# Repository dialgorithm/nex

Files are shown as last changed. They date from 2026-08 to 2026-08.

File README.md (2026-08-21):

# nex

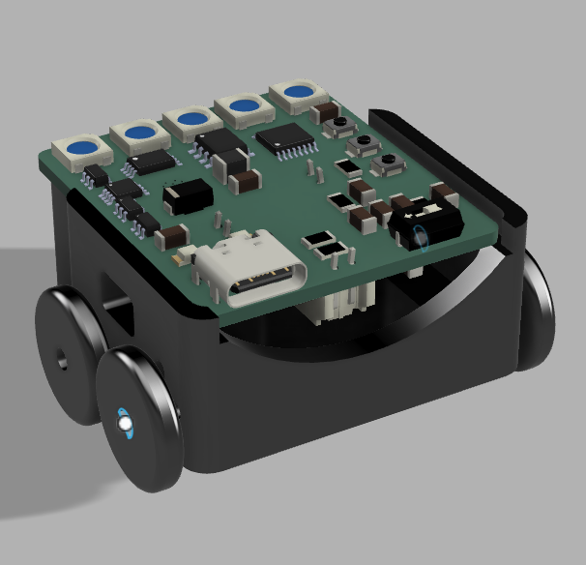
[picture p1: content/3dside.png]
3d side


**nex** is a swarm robotics project built around **ESP32-based bots**, computer vision, AprilTags, and a custom 4-layer PCB. The goal is to have multiple small bots identify and communicate with each other while working together as a swarm.

it features:

- ESP32-WROOM in each bot for wireless communication
- Luckfox Lyra Zero W for computer vision
- AprilTags for identifying individual bots
- Custom 4-layer PCB designed in KiCad

## how it works

each bot has an **ESP32-WROOM** which handles communication between the bots and provides the wireless connection. Each bot also has its own AprilTag, giving the vision system a way to identify which bot it is looking at.

the **Luckfox Lyra Zero W** handles the computer vision side. It detects the AprilTags and uses their position and orientation to work out where the other bots are.

this allows the bots to know who is around them and where they are, which forms the basis for the swarm behaviour.

## KiCad

the electronics are built around a custom **4-layer PCB**, designed to keep the different parts of the bot connected without needing a large amount of external wiring.

| schematic | PCB |
| :---: | :---: |
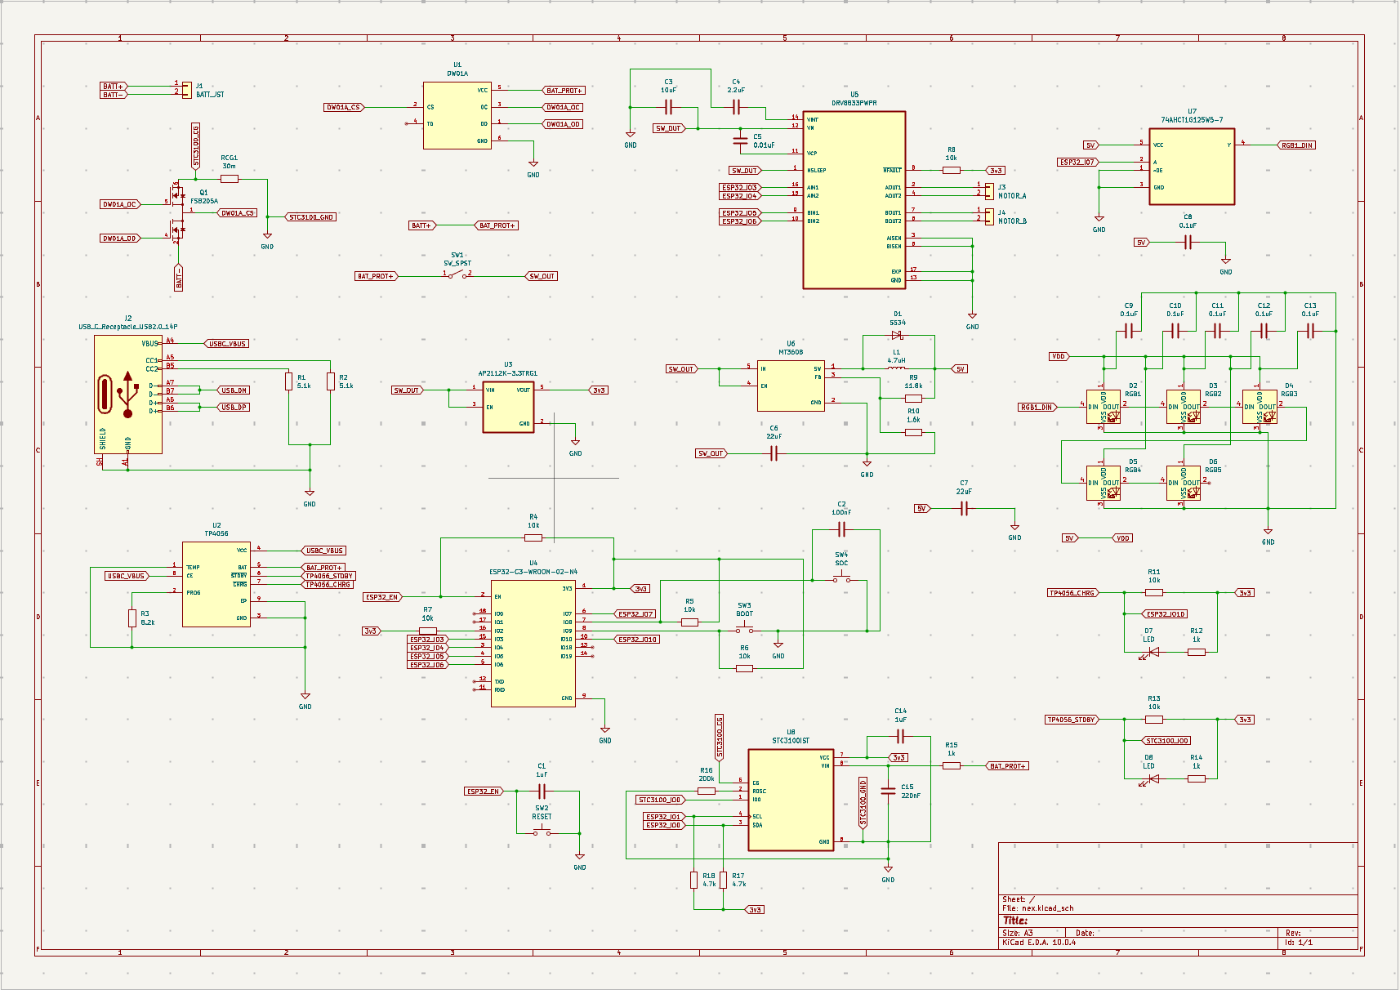
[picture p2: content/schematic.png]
schematic
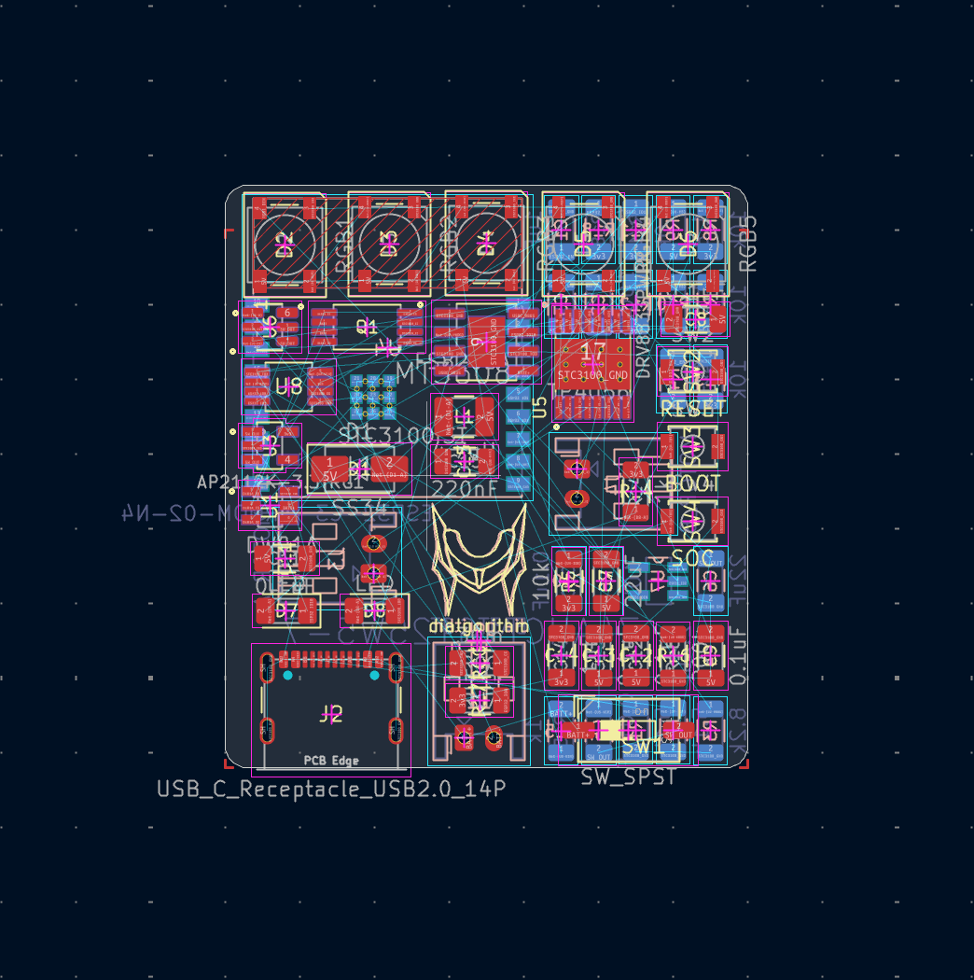
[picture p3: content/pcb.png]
PCB
|  |  |

| PCB mockup top | PCB mockup bottom |
| :---: | :---: |
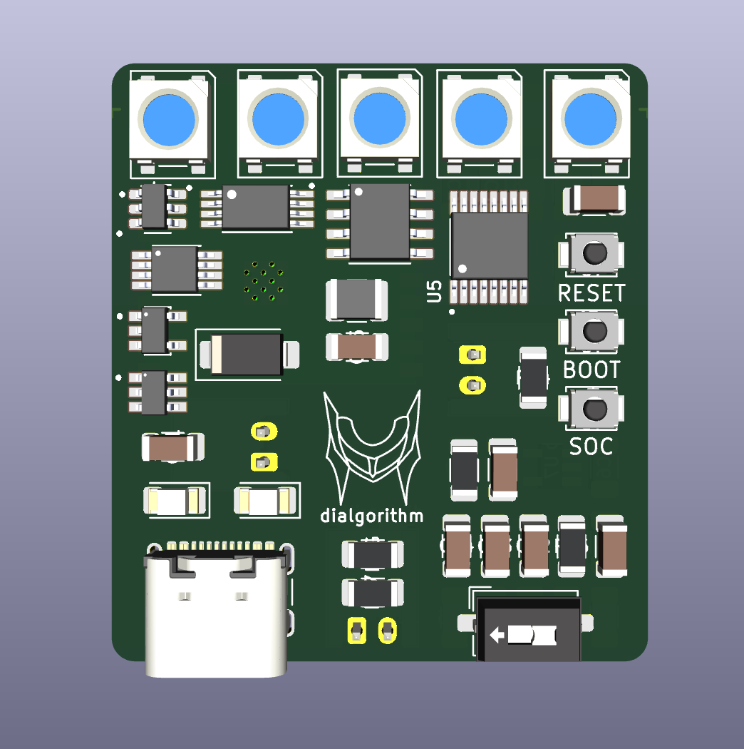
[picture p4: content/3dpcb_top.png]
top
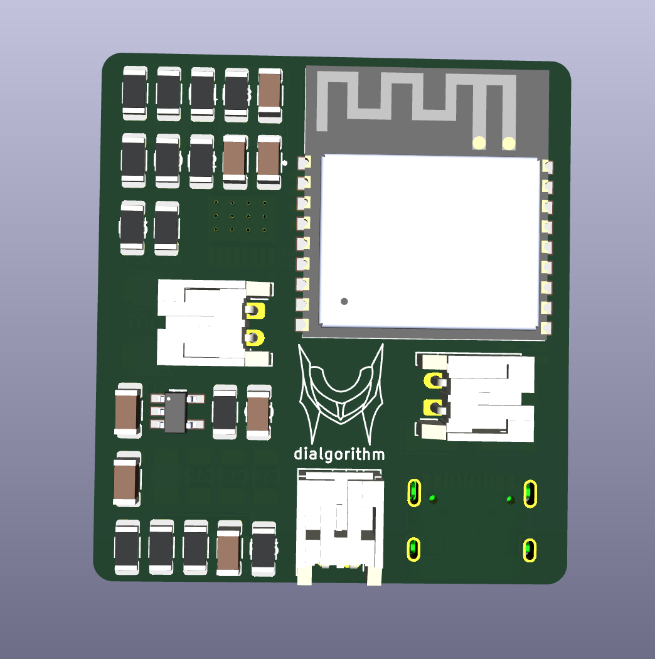
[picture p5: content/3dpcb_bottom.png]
bottom
|  |  |

## Fusion

the mechanical design and overall bot layout were modelled in Fusion.

| top | side | bottom |
| :---: | :---: | :---: |
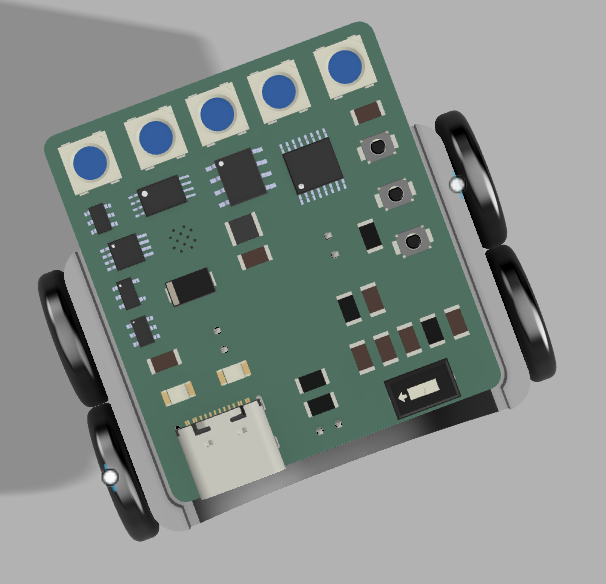
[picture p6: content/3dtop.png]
3d top
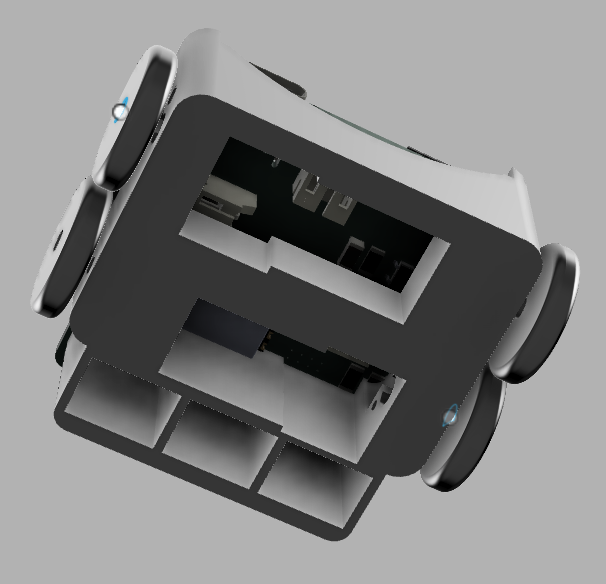
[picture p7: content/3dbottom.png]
3d bottom
|  | 3d side |  |

## BOM

the complete bill of materials is available in [`bom.csv`](bom.csv).

## firmware

firmware is not included yet. The software will be added after the physical bots are built and the hardware can be tested and debugged.

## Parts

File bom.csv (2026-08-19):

Item | Quantity | Cost | Source
PCB | 10 | $34 | https://robu.in/product/online-pcb-manufacturing-service/
1uF 1206 SMD | 20 | $5 | https://www.amazon.in/1UF-1206-Ceramic-Capacitor-20Pcs/dp/B0DYJTLFDL
0.1uF 1206 SMD | 60 | $4.2 | https://www.amazon.in/Steko-Capacitor-Tolerance-Electronic-Component/dp/B0D3D8HW51
220nF 1206 SMD | 10 | $2.7 | https://www.amazon.in/220NF-Ceramic-Capacitor-WALSIN-0-22UF/dp/B0GDDTYT3W
100nF 1206 SMD | 10 | $3.25 | https://www.amazon.in/e4u-Ceramic-Capacitor-SMD-1206-Package/dp/B09QGXCYWB
10uF 1206 SMD | 10 | $3 | https://www.amazon.in/10uF-Ceramic-Capacitor-25pcs-CL31A106KAHNNNE/dp/B0GDF194MR
2.2uF 1206 SMD | 10 | $2.6 | https://www.amazon.in/2-2uF-0603-Ceramic-Capacitor-pack/dp/B0FCSH5MKH
0.01uF 1206 SMD | 10 | $2 | https://www.amazon.in/Steko-Capacitor-Tolerance-Electronic-Component/dp/B0FRZ43N35
22uF 1206 SMD | 20 | $4 | https://www.amazon.in/22%C2%B5F-SMD-Capacitor-Package-Original/dp/B0F4RK46GL
SS34 Diode | 10 | $2.1 | https://www.amazon.in/SS34-SMA-Schottky-Diode-Package-DO-214AC/dp/B092R2K27Q
WS2812B-2020 | 50 | $4.2 | https://robu.in/product/sme-ws2812b-2020-addressable-rgb-pixel-led-worldsemi/
RED LED 1206 SMD | 10 | $2.3 | https://www.amazon.in/Steko-Electronic-Component-Multipurpose-Backlight/dp/B0FZJ1QWR9
GREEN LED 1206 SMD | 10 | $2.3 | https://www.amazon.in/Steko-Electronic-Component-Multipurpose-Backlight/dp/B0FZJ293TX
JST Kit | 30 | $6.3 | https://www.amazon.in/MTRoyaldia-560PCS-Connector-Housing-Adapter/dp/B0GTPGBC7S
Crimping tool | 1 | $3.2 | https://www.amazon.in/BUILDSKILL-crimping-ergonomic-heavy-duty-telephone/dp/B0DVLLL2YG
USB-C Receptacle | 10 | $3.8 | https://robu.in/product/type-c-31-m-31-hroparts-5a-1-surface-mount-right-angle-16p-female-30%E2%84%8380%E2%84%83-type-c-smd-usb-connectors-rohs
4.7uH 1210 SMD | 10 | $1.6 | https://robu.in/product/lqh32pn4r7nn0l-murata-lqh32pn4r7nn0l-power-inductor-smd-4-7-%C2%B5h-1-a-shielded-1-a-lqh32pn_n0-series-1210-3225-metric/
5.1k 1206 SMD | 20 | $2.3 | https://www.amazon.in/5-1K-ohm-Resistor-1206-Package/dp/B09N427SVD
1.6k 1206 SMD | 10 | $2.4 | https://www.amazon.in/Wizzo-Tolerance-Electronic-Components-Multipurpose/dp/B0D8L24V6L
10k 1206 SMD | 70 | $2.1 | https://www.amazon.in/100PCS-Ohm-1206-Size-Resistors/dp/B07HQLRHY1
1k 1206 SMD | 30 | $2.1 | https://www.amazon.in/Resistor-1206-Package-Tolerance-Pack/dp/B0H9JFBG6L
200k 1206 SMD | 10 | $2.1 | https://www.amazon.in/Wenray-Pieces-Kilo-Tolerance-Resistor/dp/B0HB4ZV65M
4.7k 1206 SMD | 20 | $2.1 | https://www.amazon.in/Resistor-1206-Package-4-7K-Tolerance/dp/B0H9JCZXBB
8.2k 1206 SMD | 10 | $2.7 | https://www.amazon.in/e4u-0-25W-SMD-1206-Package-Resistor/dp/B0813T2HSR
11.8k 1206 SMD | 10 | $0.42 | https://robu.in/product/mfr-25fbf52-11k8-yageo-res-11k8-0-25w-axial-metal-film/
30m SMD | 10 | $1.3 | https://robu.in/product/0-03-ohm-3w-surface-mount-sense-resistor/
SW SPST | 10 | $3.9 | https://robu.in/product/2-54-1p-tppt-shou-han-1-digit-spst-24v-black-25ma-3000-times-flat-toggle-slotted-smd-dip-switches-rohs/
DW01A | 10 | $0.65 | https://robu.in/product/dw01a-4-3v-lithium-ion-lithium-polymer-battery-protection-ic-6pin-sot-23/
TP4056 | 10 | $3.2 | https://www.amazon.in/TP4056-10Pcs-SOP8-LP4056H-4056/dp/B0G4DXKGXC
MT3608 | 10 | $2.2 | https://robu.in/product/mt3608-xian-aerosemi-tech-boost-type-adjustable-2a-2v24v-sot-23-6-dc-dc-converters-rohs/
74AHCT1G125W5-7 | 10 | $3.2 | https://robu.in/product/74ahc1g125qw5-7-diodes-incorporated-8ma-1-2v5-5v-8ma-1-sot-25-buffers-drivers-receivers-transceivers-rohs/
AP2112K-3.3TRG1 | 10 | $14.2 | https://www.desertcart.in/products/808664101-10pcs-ap2112k-3-3-sot23-5-ap2112k-3-3trg1-3
DRV8833PWPR | 10 | $26 | https://www.desertcart.in/products/525842950-reland-sun-10pcs-drv8833pwpr-htssop16-drv8833pwp-htssop-16-drv8833-tssop16
Pi Zero Case | 1 | $3 | https://www.amazon.in/REES52-RS1009-01-Raspberry-Zero-Starter/dp/B07L93QMD6
Pi Zero Camera | 1 | $3 | https://robu.in/product/5mp-raspberry-pi-camera-module-w-hbv-ffc-cable/
Luckfox Lyra Zero W (pi zero unavailable everywhere) | 1 | $41 | https://robu.in/product/luckfox-lyra-zero-w-micro-linux-development-board/
Tripod | 1 | $2.2 | https://www.amazon.in/Kratos-Extendable-Bluetooth-Multifunctional-OnePlus/dp/B0G4MZ85QG
Cable | 1 | $2 | https://www.amazon.in/Portronics-Charging-Transfer-Aluminium-compatible/dp/B0FVYTSCVY
a4 matte vinyl printing for apriltags | 8 | $8.5 | https://www.vistaprint.in/marketing-materials/labels-stickers/sheet-stickers
acrylic mounting plates for apriltags | 8 | $8.6 | https://robu.in/product/online-laser-cutting-service/
glue gun | 1 | $5.4 | https://www.amazon.in/IBELL-GG30-01-High-Heavy-Sticks/dp/B08863MZ8H
glue sticks | 1 | $3.5 | https://www.amazon.in/Themisto-7mm-glue-stick-pack/dp/B0CK27HQ2F
utility knife | 1 | $2.9 | https://www.amazon.in/Taparia-UK-3-Steel-Utility-Silver/dp/B073SWWKWJ
3d printed parts + shipping | 1 | $11 | https://printlegion.hackclub.com
Cost for Each Nex bot:
B3U-1000P | 3 | $1.2 | https://robu.in/product/b3u-1000p-omron-2-5mm-1-6mm-round-button-50ma-vertical-welding-3mm-spst-1-53n-12v-smd2-5x3mm-tactile-switches-rohs/
ESP32-C3-WROOM-02-N4 | 1 | $2.73 | https://robu.in/product/espressif-esp32-c3-wroom-02-n4-module/
STC3100IST | 1 | $2.55 | https://robu.in/product/stc3100ist-stmicroelectronics-battery-li-ion-supervisor-monitor-ic-i2c-interface-1-cell-2-7-v-to-5-5-v-supply-msop-8/
WLY602030 3.7V 300mAh | 1 | $1.83 | https://robu.in/product/300mah-pcm-protected-micro-li-po-battery/
N20-3V-100 RPM | 2 | $2.52 | https://robocraze.com/products/robocraze-dc6v-100rpm-gm12-n20-miniature-gear-motor-with-metal-gear
Total | 8 | $118 | -
Final Total | - | ~$368 | -

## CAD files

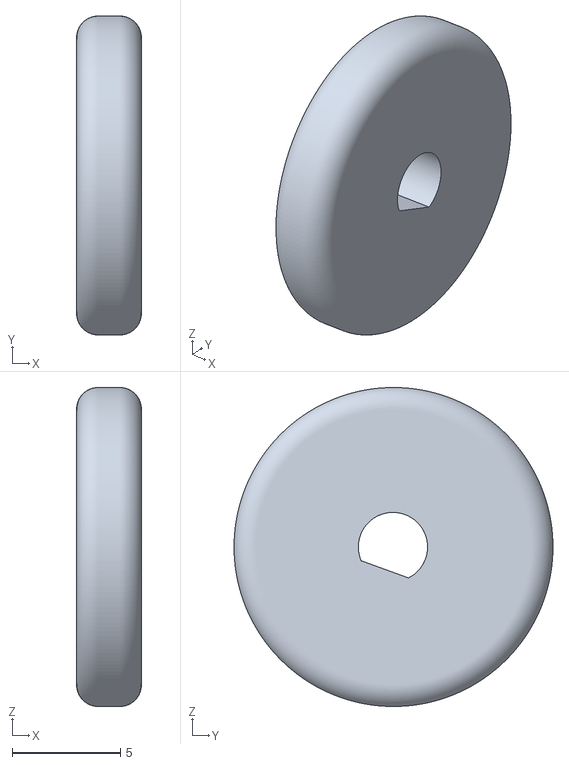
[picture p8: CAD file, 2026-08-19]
CAD/motor_wheel.stl
3.00 x 14.7 x 14.7

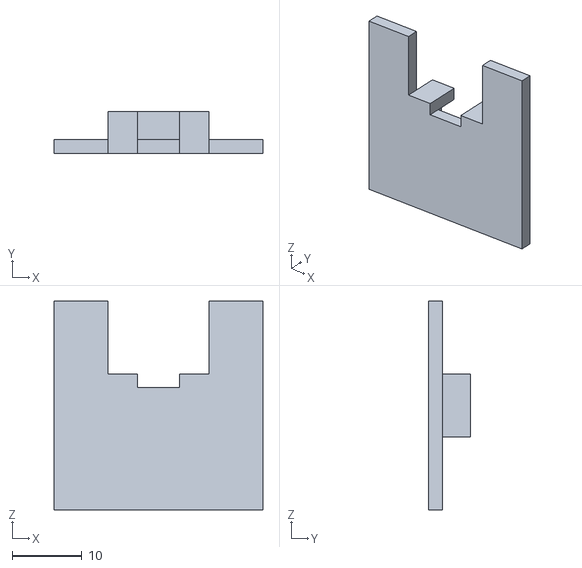
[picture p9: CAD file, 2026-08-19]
CAD/apriltag_mount.stl
30.0 x 6.00 x 30.0

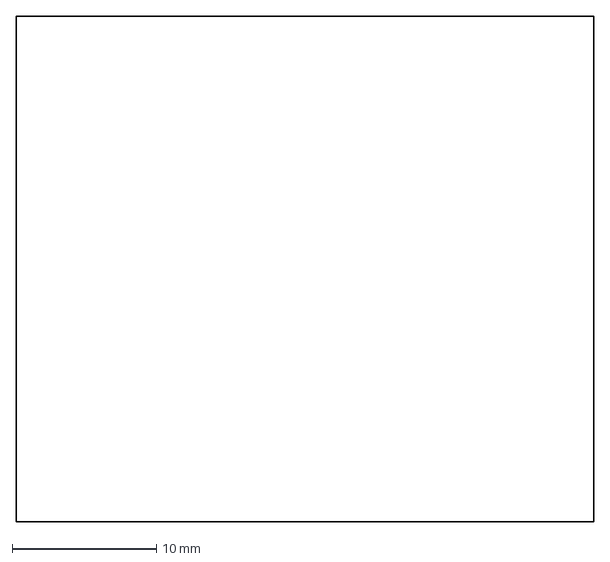
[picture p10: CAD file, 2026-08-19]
CAD/apriltag_mountpanel.dxf
40.0 x 35.0 mm

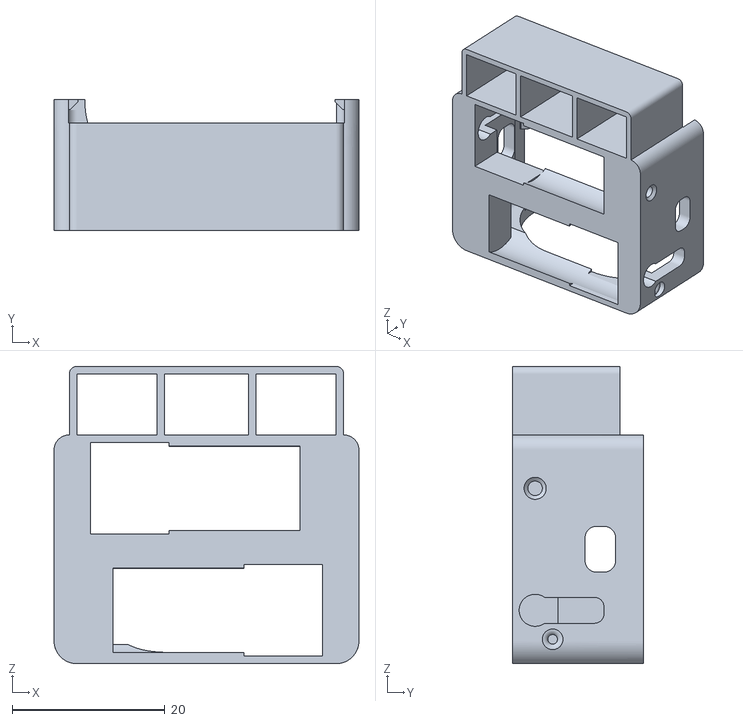
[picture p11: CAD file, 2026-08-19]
CAD/body.stl
40.0 x 17.2 x 39.0

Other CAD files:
CAD/screw_wheel.stl
CAD/main.f3z

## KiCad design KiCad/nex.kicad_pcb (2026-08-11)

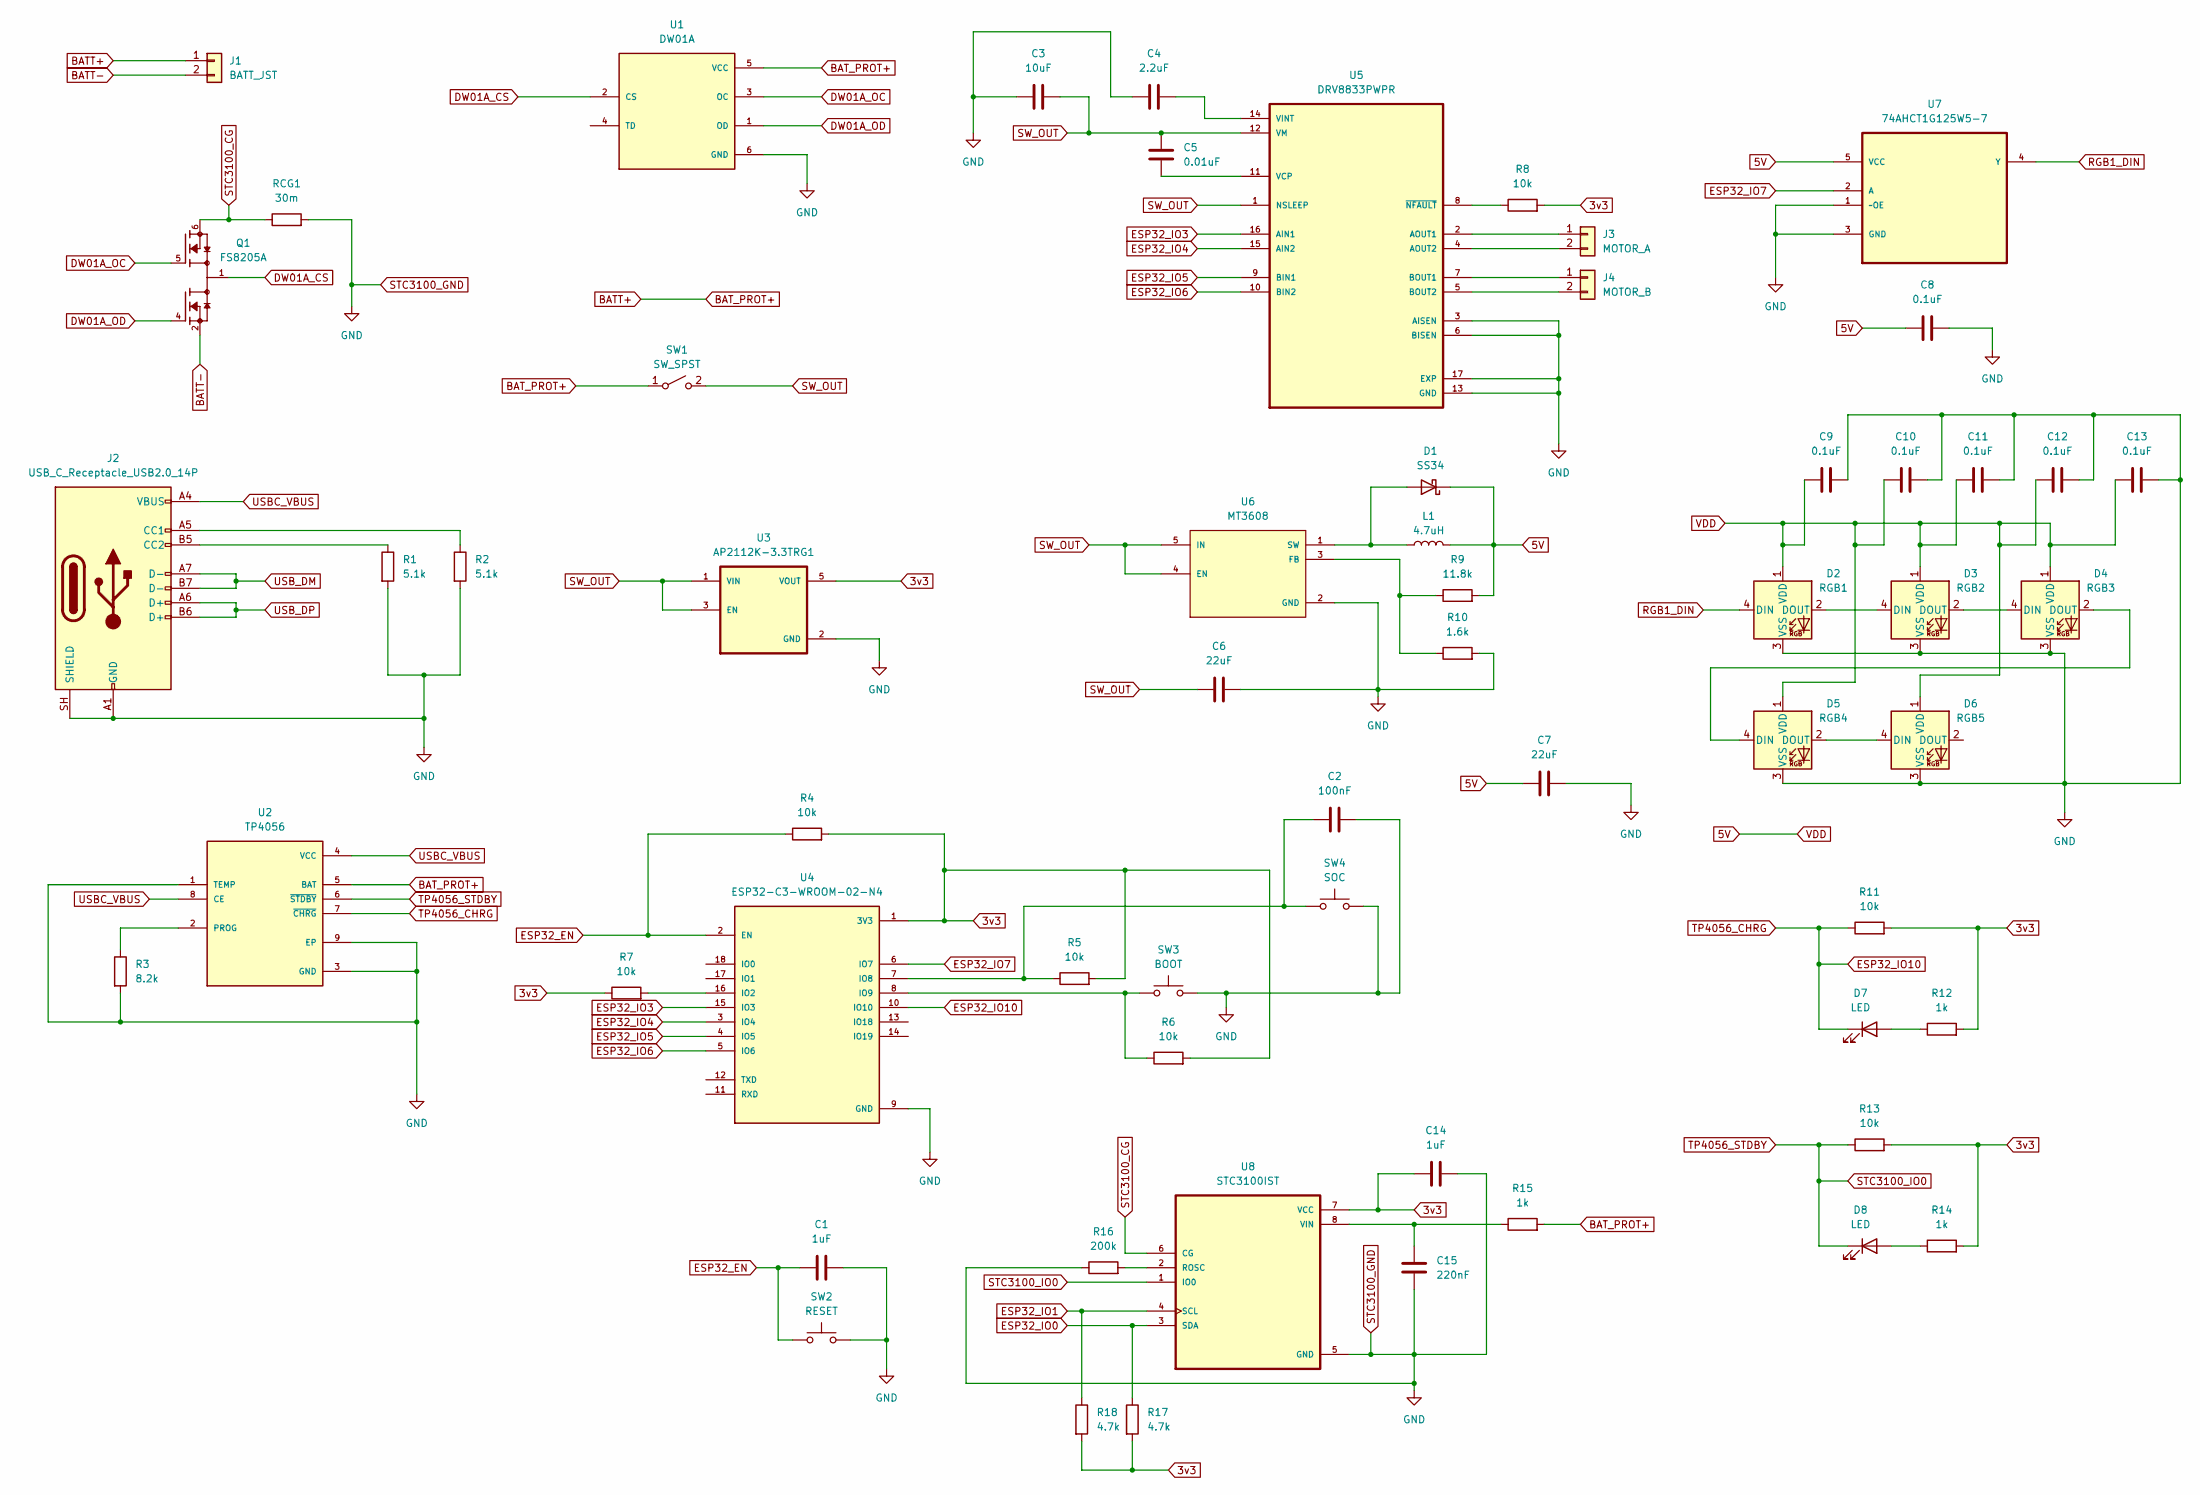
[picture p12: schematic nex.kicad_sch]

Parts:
C1, C14: 1uF; C_1206_3216Metric
C2: 100nF; C_1206_3216Metric
C3: 10uF; C_1206_3216Metric
C4: 2.2uF; C_1206_3216Metric
C5: 0.01uF; C_1206_3216Metric
C6, C7: 22uF; C_1206_3216Metric
C8, C9, C10, C11, C12, C13: 0.1uF; C_1206_3216Metric
C15: 220nF; C_1206_3216Metric
D1: SS34; D_SMA
D2: RGB1; LED_WS2812B_PLCC4_5.0x5.0mm_P3.2mm
D3: RGB2; LED_WS2812B_PLCC4_5.0x5.0mm_P3.2mm
D4: RGB3; LED_WS2812B_PLCC4_5.0x5.0mm_P3.2mm
D5: RGB4; LED_WS2812B_PLCC4_5.0x5.0mm_P3.2mm
D6: RGB5; LED_WS2812B_PLCC4_5.0x5.0mm_P3.2mm
D7, D8: LED; LED_1206_3216Metric
J1: BATT_JST; JST_PH_S2B-PH-K_1x02_P2.00mm_Horizontal
J2: USB_C_Receptacle_USB2.0_14P; USB_C_Receptacle_GCT_USB4105-xx-A_16P_TopMnt_Horizontal
J3: MOTOR_A; JST_PH_S2B-PH-K_1x02_P2.00mm_Horizontal
J4: MOTOR_B; JST_PH_S2B-PH-K_1x02_P2.00mm_Horizontal
L1: 4.7uH; L_1210_3225Metric
Q1: FS8205A; SOP65P640X120-8N; PARTREV 1.7
R1, R2: 5.1k; R_1206_3216Metric
R3: 8.2k; R_1206_3216Metric
R4, R5, R6, R7, R8, R11, R13: 10k; R_1206_3216Metric
R9: 11.8k; R_1206_3216Metric
R10: 1.6k; R_1206_3216Metric
R12, R14, R15: 1k; R_1206_3216Metric
R16: 200k; R_1206_3216Metric
R17, R18: 4.7k; R_1206_3216Metric
RCG1: 30m; R_1206_3216Metric
SW1: SW_SPST; SW_DIP_SPSTx01_Slide_6.7x4.1mm_W6.73mm_P2.54mm_LowProfile_J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
SW2: RESET; SW_SPST_B3U-1000P
SW3: BOOT; SW_SPST_B3U-1000P
SW4: SOC; SW_SPST_B3U-1000P
U1: DW01A; SOT95P280X145-6N; PARTREV 1.8
U2: TP4056; SOP127P600X175-9N
U3: AP2112K-3.3TRG1; SOT95P285X140-5N; PARTREV 2-2
U4: ESP32-C3-WROOM-02-N4; MODULE_ESP32-C3-WROOM-02-H4
U5: DRV8833PWPR; IC_DRV8833PWPR; PARTREV E
U6: MT3608; SOT95P280X145-6N; PARTREV 1.0
U7: 74AHCT1G125W5-7; SOT95P280X140-5N; MPN 74AHCT1G125W5-7
U8: STC3100IST; SOIC65P490X110-8N

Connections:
3v3: C14.1, R4.2, R5.2, R6.2, R7.1, R8.2, R11.2, R12.2, R13.2, R14.2, R17.2, R18.2, U3.5 (VOUT), U4.1 (3V3), U8.7 (VCC)
5V: C7.1, C8.1, C9.1, C10.1, C11.1, C12.1, C13.1, D1.1 (K), D2.1 (VDD), D3.1 (VDD), D4.1 (VDD), D5.1 (VDD), D6.1 (VDD), L1.2, R9.2, U7.5 (VCC)
BATT+: J1.1, R15.2, SW1.1 (A), U1.5 (VCC), U2.5 (BAT)
BATT-: J1.2, Q1.2, Q1.3
DW01A_CS: Q1.1, Q1.8, U1.2 (CS)
DW01A_OC: Q1.5, U1.3 (OC)
DW01A_OD: Q1.4, U1.1 (OD)
ESP32_EN: C1.1, R4.1, SW2.1, U4.2 (EN)
ESP32_IO0: R17.1, U8.3 (SDA)
ESP32_IO1: R18.1, U8.4 (SCL)
ESP32_IO3: U4.15 (IO3), U5.16 (AIN1)
ESP32_IO4: U4.3 (IO4), U5.15 (AIN2)
ESP32_IO5: U4.4 (IO5), U5.9 (BIN1)
ESP32_IO6: U4.5 (IO6), U5.10 (BIN2)
ESP32_IO7: U4.6 (IO7), U7.2 (A)
ESP32_IO10: D7.1 (K), R11.1, U2.7 (~CHRG), U4.10 (IO10)
unnamed: D1.2 (A), L1.1, U6.1 (SW)
unnamed: D2.2 (DOUT), D3.4 (DIN)
unnamed: D3.2 (DOUT), D4.4 (DIN)
unnamed: D4.2 (DOUT), D5.4 (DIN)
unnamed: D5.2 (DOUT), D6.4 (DIN)
unnamed: D7.2 (A), R12.1
unnamed: D8.2 (A), R14.1
unnamed: J2.A5 (CC1), R2.1
unnamed: J2.B5 (CC2), R1.1
unnamed: J3.1, U5.2 (AOUT1)
unnamed: J3.2, U5.4 (AOUT2)
unnamed: J4.1, U5.7 (BOUT1)
unnamed: J4.2, U5.5 (BOUT2)
unnamed: R3.1, U2.2 (PROG)
unnamed: R7.2, U4.16 (IO2)
unnamed: C2.1, R5.1, SW4.1, U4.7 (IO8)
unnamed: R6.1, SW3.1, U4.8 (IO9)
unnamed: C5.1, U5.11 (VCP)
unnamed: C4.2, U5.14 (VINT)
unnamed: R8.1, U5.8 (~NFAULT)
unnamed: R9.1, R10.1, U6.3 (FB)
unnamed: R16.2, U8.2 (ROSC)
unnamed: C15.2, R15.1, U8.8 (VIN)
RGB1_DIN: D2.4 (DIN), U7.4 (Y)
STC3100_CG: Q1.6, Q1.7, RCG1.1, U8.6 (CG)
STC3100_GND: C1.2, C2.2, C3.1, C4.1, C6.2, C7.2, C8.2, C9.2, C10.2, C11.2, C12.2, C13.2, C14.2, C15.1, D2.3 (VSS), D3.3 (VSS), D4.3 (VSS), D5.3 (VSS), D6.3 (VSS), J2.A1 (GND), J2.A12 (GND), J2.B1 (GND), J2.B12 (GND), J2.SH (SHIELD), R1.2, R2.2, R3.2, R10.2, R16.1, RCG1.2, SW2.2, SW3.2, SW4.2, U1.6 (GND), U2.1 (TEMP), U2.3 (GND), U2.9 (EP), U3.2 (GND), U4.9 (GND), U4.19 (GND), U4.20 (GND), U4.21 (GND), U4.22 (GND), U4.23 (GND), U4.24 (GND), U4.25 (GND), U4.26 (GND), U4.27 (GND), U4.28 (GND), U4.29 (GND), U4.30 (GND), U4.31 (GND), U4.32 (GND), U4.33 (GND), U4.34 (GND), U4.35 (GND), U4.36 (GND), U4.37 (GND), U4.38 (GND), U4.39 (GND), U5.3 (AISEN), U5.6 (BISEN), U5.13 (GND), U5.17 (EXP), U6.2 (GND), U7.1 (~OE), U7.3 (GND), U8.5 (GND)
STC3100_IO0: D8.1 (K), R13.1, U2.6 (~STDBY), U8.1 (IO0)
SW_OUT: C3.2, C5.2, C6.1, SW1.2 (B), U3.1 (VIN), U3.3 (EN), U5.1 (NSLEEP), U5.12 (VM), U6.4 (EN), U6.5 (IN)
USBC_VBUS: J2.A4 (VBUS), J2.A9 (VBUS), J2.B4 (VBUS), J2.B9 (VBUS), U2.4 (VCC), U2.8 (CE)
USB_DM: J2.A7 (D-), J2.B7 (D-)
USB_DP: J2.A6 (D+), J2.B6 (D+)

Board: 2 copper layers, 60 parts (27 on the bottom side), 47 nets, no tracks yet.

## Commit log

2026-08-11 4 layer update
    [bom.csv, nex.kicad_pcb]
2026-08-19 print prod
    [apriltag_mount.stl, apriltag_mountpanel.dxf, body.stl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]
